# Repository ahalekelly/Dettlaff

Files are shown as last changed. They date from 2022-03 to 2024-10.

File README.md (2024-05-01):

# Dettlaff

Dettlaff is a modular controller system for brushless flywheel Nerf blasters



## Flashing Firmware over USB:
1. Install [VSCode]([https://platformio.org/install/ide?install=vscode](https://code.visualstudio.com/)) and [git](https://git-scm.com/downloads). On Windows you have to install [drivers for the CH340 USB adapter](https://learn.sparkfun.com/tutorials/how-to-install-ch340-drivers/all#drivers-if-you-need-them)
2. Download this repository, under the green Code button on this page, then in VSCode go to File > Open Folder and select the Dettlaff folder. If you downloaded the zip file then you need to select the inner Dettlaff folder, not the outer one. It will ask you to install the PlatformIO extension if you don't already have it
3. Power Dettlaff from a battery, and plug the USB adapter into your computer. There are 6 pins on the programmer that connect to 6 holes on the edge of Dettlaff, line up the pin with the square pad on the programmer with the hole with the square pad on Dettlaff, and insert the pins into the holes. Use the weight of the USB cable to apply a little torque to the adapter so that the pins make good contact, or solder a female header connector into the Dettlaff holes.
4. Update src/CONFIGURATION.h with your wifi name and password, and version of the board that you have, and any other settings for your blaster and then press the Upload button (arrow on the bottom toolbar)

USB Troubleshooting:

Dettlaff should enter upload mode automatically, but if it doesn't, the button on board can do it manually
* Try holding the button on the board as you hit upload, and keep holding until it says Uploading
* Try holding the button as you plug in the battery to Dettlaff, then letting go

## Flashing Firmware over WiFi:

1. First, flash a firmware over USB with your wifi SSID and password
2. In VSCode, change the Project Environment (button that says "Default" on the bottom toolbar) to "env:esp32-wifi"
3. Turn on or power cycle (unplug, wait a few seconds, and plug back in) your Dettlaff
4. Hit Upload within a few minutes of power cycling

## Wiring
* Look up in boards_config.h which pins to use for your version of Dettlaff
* Connect each switch between the numbered pin (yellow wire) and the - pin (black wire) on each connector
* Dettlaff is designed for the ESCs that we sell, but ESC connectors are not standardized. If you are using a different ESC, double check that all the pins on the ESC output match the pins on the ESC before connecting them! **This can fry your Dettlaff!**
* If you have a power switch, solder it between the - pin and the SHDN (shutdown) pin
* Solder your Dettlaff to the ESC and LiPo battery like below. The ground wire should go from the battery to the ESC, then from the ESC to the Dettlaff
imgonline-com-ua-twotoone-U4kocRnWdYJE

* Use the capacitors that came with the Dettlaff and the ESC. Use of capacitors with lower capacity or higher ESR could result in damage and will void your warranty

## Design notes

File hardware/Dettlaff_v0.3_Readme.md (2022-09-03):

## Flashing Instructions:
1. [Install VSCode and the PlatformIO Extension](https://platformio.org/install/ide?install=vscode)
2. Linux and Mac come with the CH340G serial adapter drivers, on Windows you can install them from [here](https://sparks.gogo.co.nz/assets/_site_/downloads/CH34x_Install_Windows_v3_4.zip)
3. Use `git clone`, Github Desktop, or VSCode to download this repository. **Github's Download Zip button does not include the required libraries!**
4. Open the Dettlaff directory in VSCode, set your WiFi SSID and password in the source code so that you can program over wifi later
5. On the bottom bar, click `Default (Dettlaff)` and select `env:esp32-usb` for USB programming
6. Power your Dettlaff from a battery, connect the USB-C adapter to your computer, insert the adapter pins into the holes and let the adapter rest at an angle (no need to solder), and hit the PlatformIO: Upload button on the bottom bar (the arrow)

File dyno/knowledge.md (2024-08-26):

# dyno Knowledge

## Purpose
- The dyno script is used for plotting dynamometer data for the Dettlaff project

## Key Features
- Reads data from a log file or serial port
- Supports multiple motors (determined dynamically from the data)
- Plots voltage, current, throttle, and RPM data
- Saves plots as PNG files

## Usage
- Can be run with a log file: `venv/bin/python dyno.py [logfile]`
- Can also capture real-time data from a serial port

## Dependencies
- matplotlib
- pyserial

## Environment
- Uses a Python virtual environment (venv)
- Requirements are specified in requirements.txt

## Important Notes
- The script doesn't exit until the user quits it
- Code changes cannot be applied while the script is running

## TODO
- Consider optimizing the plot saving process (currently saves twice)
- Explore adding more analysis features or statistics from the data

# Python Virtual Environment Instructions:

`cd` to the dyno directory

## Setup:

Create a new venv called venv:
    python3 -m venv venv

Install requirements inside that venv:
    venv/bin/python -m pip install -r requirements.txt

## Usage:

To capture and plot the serial telemetry, run 
    venv/bin/python dyno.py

If you want to also print the serial data while it's coming in:
    venv/bin/python dyno.py -p

To regenerate the plot for an existing log file:
    venv/bin/python dyno.py 2024-08-25_21:30:04.log

To regenerate the plots for all log files:
    venv/bin/python dyno.py all

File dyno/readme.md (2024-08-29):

# Dettlaff Dynamometer

Captures telemetry data over the serial bus, saves it to a .log file, and plots it to a .png file



## Setup:

Make sure you have python installed

`cd` to the dyno directory

Create a new venv called venv and install the requirements:

    python3 -m venv venv && venv/bin/python -m pip install -r requirements.txt

## Usage Examples:

`cd` to the dyno directory

To capture and plot the serial telemetry:

    venv/bin/python dyno.py

To regenerate the png files for all log files - the formatting on the real-time plots is a little off right now, this will fix them

    venv/bin/python dyno.py -a

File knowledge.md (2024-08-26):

# Dettlaff Project Knowledge

## Project Overview
- Dettlaff is a modular controller system for brushless flywheel Nerf blasters
- The project includes hardware designs and software for controlling and monitoring the blaster

## Key Components
- dyno: A Python script for plotting dynamometer data
- src: Contains the main source code for the controller
- hardware: Contains hardware designs and documentation

## Development Environment
- Uses PlatformIO for embedded development
- Python virtual environment for dyno script

## Flashing Instructions
- Firmware can be flashed over USB or WiFi
- Requires VSCode with PlatformIO extension

## Wiring
- Specific wiring instructions are provided in the README
- Caution is needed when connecting ESCs to avoid damage

## TODO
- Add more detailed information about the src and hardware components as they are explored

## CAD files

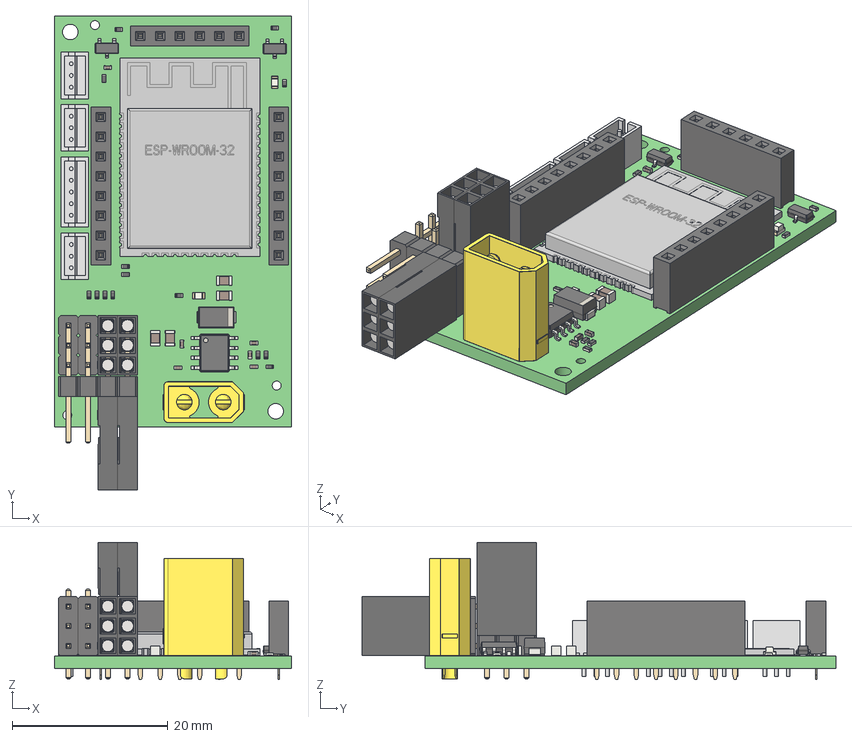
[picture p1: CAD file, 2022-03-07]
hardware/Core_v0.1/Dettlaff_Core_v0.1.step
30.5 x 60.9 x 17.6 mm
RapidstrikePCB PCB
PinHeader_3x04_P2.54mm_Horizontal
DS1071-1x3 x 4

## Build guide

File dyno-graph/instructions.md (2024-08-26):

Python Virtual Environment Instructions:

`cd` to the dyno-graph directory

# Setup:

Create a new venv called venv:
    python3 -m venv venv

Install requirements inside that venv:
    venv/bin/python -m pip install -r requirements.txt

# Usage:

To capture and plot the serial telemetry, run 
    venv/bin/python dyno-graph.py

If you want to also print the serial data while it's coming in:
    venv/bin/python dyno-graph.py -p

To regenerate the plot for an existing log file:
    venv/bin/python dyno-graph.py 2024-08-25_21:30:04.log

To regenerate the plots for all log files:
    venv/bin/python dyno-graph.py -a

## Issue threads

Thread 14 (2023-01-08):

To Do: Design adapter board for 2 individual ESCs

ahalekelly, 2023-01-08:

Daehder, 2023-01-10:
You may not need a board; didn't Eli say that you could get a Chinese factory to crimp cables for you? It's pretty simple to make a simple wiring adaptor for this; I can post pictures later

ahalekelly, 2023-01-11:
Oh yeah that's a pretty good idea! I must have missed where Eli suggested that. I'll look into it.

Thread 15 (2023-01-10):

Have current firing mode update over BLE

Daehder, 2023-01-10:
It would be pretty neat if the current firing mode could update on the web app; users could then have a couple picked out to switch between and do so with a tap.

We might need a special "updatable" proto message

ahalekelly, 2023-01-11:
Good point! We definitely need a currentFiringMode parameter in the protobuf. Not sure what you mean by an "updatable" proto message

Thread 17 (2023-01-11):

To Do: Reverse pusher motor direction during braking

ahalekelly, 2023-01-11:
If the braking torque of the motor is not enough, you could apply reverse voltage instead of braking to stop it faster, or you could brake normally and reverse the motor if the pusher overruns and the cycle control switch becomes released

1) When cycle control switch is pressed, (maybe stop applying voltage to the pusher and wait a few ms to allow inductive field to decay faster than reverse polarity? should test whether this helps), then apply reverse polarity to pusher
2) After `pusherReversePolarityDuration_ms` time has passed, if cycle control switch is still pressed, remove reverse polarity and brake pusher
3) If `pusherReverseOnOverrun` config flag is set and cycle control switch is no longer pressed, maintain reverse polarity until switch becomes pressed again, then brake

I don't think we need a separate pusher control mode from the current PUSHER_MOTOR_CLOSEDLOOP mode, I think if you set duration to 0 and and the config flag to false then it would operate the same as the current mode?

It might be possible to automatically determine these variables through trial and error? Start with 0ms reverse polarity duration, and every time you see a pusher overrun, increase the duration by 1ms, up to some cap?

ahalekelly, 2023-04-17:
Another idea to prevent pusher runaway is to drive the pusher for a shorter period of time, or at a lower voltage level

ahalekelly, 2024-04-20:
This has been implemented but you have to manually tune it, and the proper value for pusherReversePolarityDuration_ms depends on how many darts you fired and whether you have darts left in the mag. We have current monitoring for the pusher now, can you determine the motor speed from the current and voltage and figure out when it's stopped?

Also there were lots of bugs when you enable pusherReverseOnOverrun and/or pusherEndReverseBrakingEarly I don't remember.

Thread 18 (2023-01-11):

To Do: Power savings

ahalekelly, 2023-01-11:
Turn off ESC and sleep Dettlaff when not in use
Notify user when battery voltage is low and then turn off ESC and sleep Dettlaff

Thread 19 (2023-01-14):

To Do: Tournament Lock

Daehder, 2023-01-14:
Ideally, we would have some way for a tournament organizer/staff to lock the fps (and rate of fire?) while still allowing the user to make and adjust firing modes.

This needs to
- Persist through a power cycle
    - both for legitimate battery changes and to foil bypass attempts
- Probably needs a timeout so that organizers don't need to publish said code or manually unlock devices
    - Doing this well could be challenging
        - A real time clock could let us set a timeout by wall clock time, but needs a battery that could complicate things
        - We could use clock time from the user's phone, but what happens if they take their phone offline and set the clock differently?
        - We could set up a server (/ serverless function?) that lets an organizer register their tournament's start time, end time, and limits, then lock the user's detlaff to that until their phone can query said server to see if it's okay to unlock?
            - This does mean someone could get stuck in a tournament lock if they leave early and can't undo it
 - Does Detlaff need to periodically advertise its state, tournament locked or not?

This might be simple enough with a code entered though the web app

This would probably be handled better through an event-organizer-specific web app; We'll see how far that gets

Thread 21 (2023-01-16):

Todo Figure out Spindown logic

Daehder, 2023-01-16:
We've got a placeholder value for spin down logic in the flywheel proto; we should figure out how we want to use that and update the documentation with units and/or an explanation when we do.

ahalekelly, 2023-01-17:
Currently the units are throttle units (scale of 0-1999) per control loop (which currently targets 1ms), [see here](https://github.com/ahalekelly/Dettlaff/blob/8f19ec03f7ce4ca9c4b30c1bc7d2380553e2c2fc/src/main.cpp#L248)
This is a crude method, we could do rpm per second, or some exponential scale like percent of current value per second, with some minimum rate so you don't asymptotically approach zero. I'll probably try the latter at some point and see whether I prefer linear or exponential. But this is a very minor feature.

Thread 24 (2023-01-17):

TODO: Flesh out UX options

Daehder, 2023-01-17:
People will want / have been asking for all sorts of ux options like rotational switches, quick setting buttons, screens, dpads like the PewPew, etc

```Also we need an option to have a button that will jump to a specific fire mode instead of cycling through modes - should this be a parameter in each FireModeEntry, or a repeated value in ControlParams? Each button will need a pin and SwitchOrientation``

_Originally posted by @ahalekelly in https://github.com/ahalekelly/Dettlaff/pull/2#discussion_r1071784529_

ahalekelly, 2023-01-21:
Yeah from an electrical/firmware standpoint, I think having one button per fire mode is equivalent to a rotary switch. So you can have one firmware mode for both of those which I described above.

Maybe people want Next Fire Mode and Prev Fire Mode buttons, instead of a single Cycle Fire Mode button? Also for a single Cycle Fire Mode button to work, you need to have a way of knowing what fire mode you're in. We should make the ESCs beep an identifiable pattern when changing to a fire mode, that's possible to do over dshot though I'm not sure you can do it while the motors are spinning. Or maybe blink the white LED in a pattern?

SuperStressed just brought up that the Hummingbird has a dual stage trigger, where the first stage is semi auto and second stage is full auto. I hadn't thought of this scenario before, need to figure out the best way to encode that in the protobuf. Maybe just a boolean to make the button for each fire mode also act as a trigger?

And we should also support rate of fire adjustment with a potentiometer. That's a super straightforward thing, just have parameters for potMinRof and potMaxRof and scale between them. I think log scale is preferable here, maybe people can just buy a log pot though?

I wasn't planning on writing the firmware for a screen, but I've been very surprised how many people have been asking for a screen. It's at least out of scope for now though. And I think dpads and rotary encoders are only useful if you have a screen?

Also, Ray brought up that it would be cool to be able to fire the blaster remotely over BLE. Changing the active fire mode is definitely required too.

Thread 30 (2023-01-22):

To Do: Screen UI

ahalekelly, 2023-01-22:
The PCB has an I2C connector for a small OLED screen or other accessories (see the [Narfduino Console](https://blastersbyairzone.com/hardware/narfduino-console/)), but I'm not currently planning on writing the UI for a screen. Lots of people seem to want it, this would be a good project for someone to take on as it's reasonably self-contained.

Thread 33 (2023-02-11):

Determine if/how ESP32 and Web BLE libraries handle packets larger than 512 bytes

Daehder, 2023-02-11:
BLE only natively supports packets as large as 512 bytes; NanoPB is calculating that the Blaster proto has a max size that exceeds 600 bytes (and I need to add support for independent RPMS for each motor, so it will get larger).

I need to look at the ESP32 library to see if it has any expected way to handle packets that are too large for one method; @ahalekelly can you check how your webBLE handles that?

If it's missing from either or they have incompatible mechanisms, we might need to implement our own version of that

ahalekelly, 2023-02-11:
Wow how did it get so big? Does it tell you the size of each field?

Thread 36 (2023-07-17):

Todo: Rev logic on startup

ahalekelly, 2023-07-17:
Need to check whether pressing the trigger soon after startup prevents ESCs from arming

Also someone requested a switch to make the flywheels idle all the time

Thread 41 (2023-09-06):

Out of memory errors?

ahalekelly, 2023-09-06:
This happens when you use bidirectional dshot and PID and wifi at the same time:

```
assert failed: rmt_isr_handle_rx_done rmt_rx.c:505 (offset > rx_chan->mem_off)

Backtrace: 0x40083715:0x3ffbf4ec |<-CORRUPTED

ELF file SHA256: ca134528bf1404a7

Rebooting...
```

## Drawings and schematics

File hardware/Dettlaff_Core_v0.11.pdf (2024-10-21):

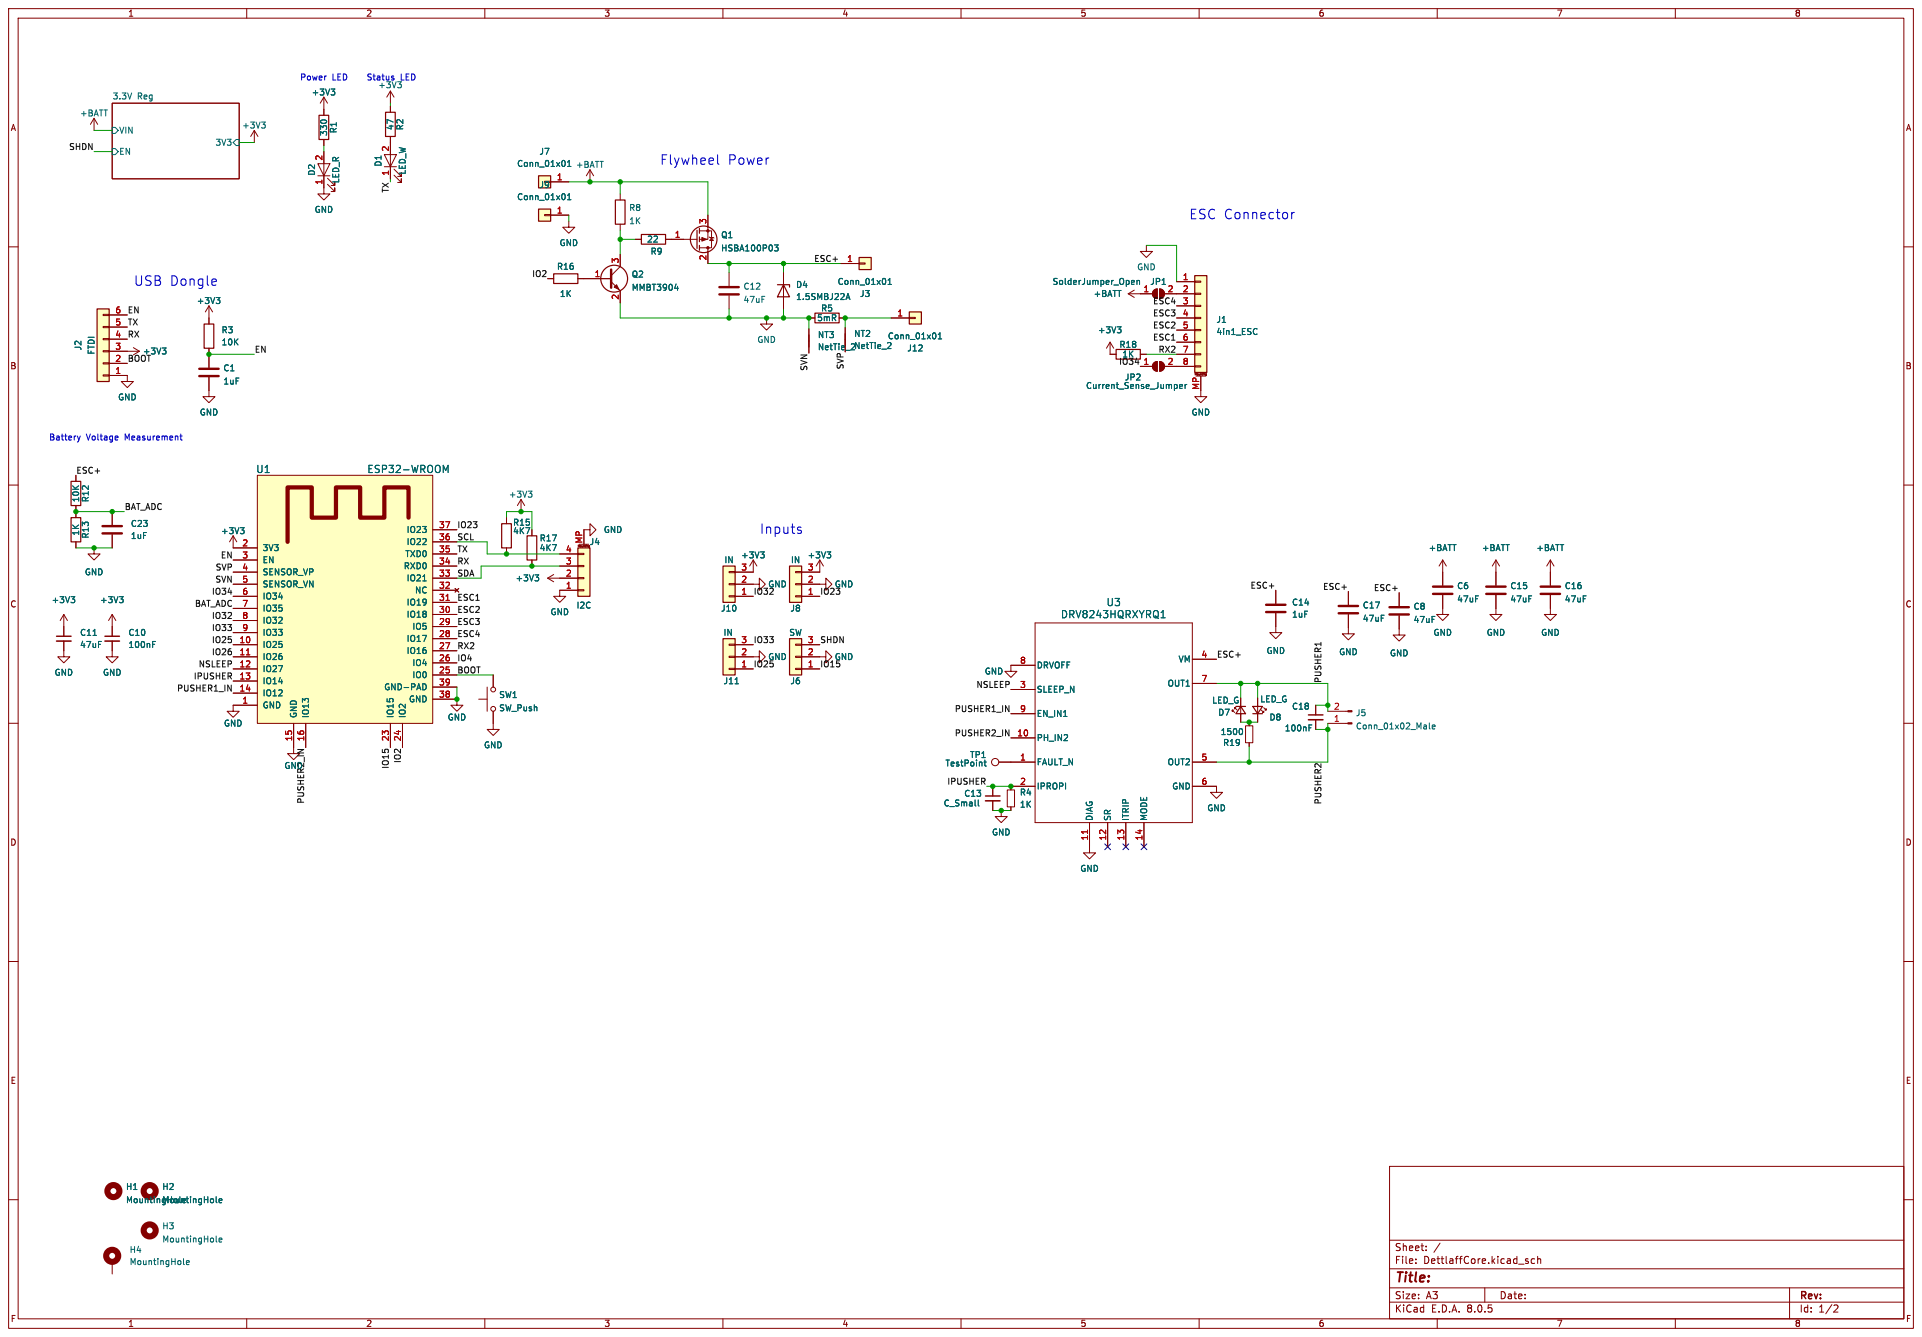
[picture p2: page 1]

2 3 Q1 HSBA100P03 +BATT GND GND GND

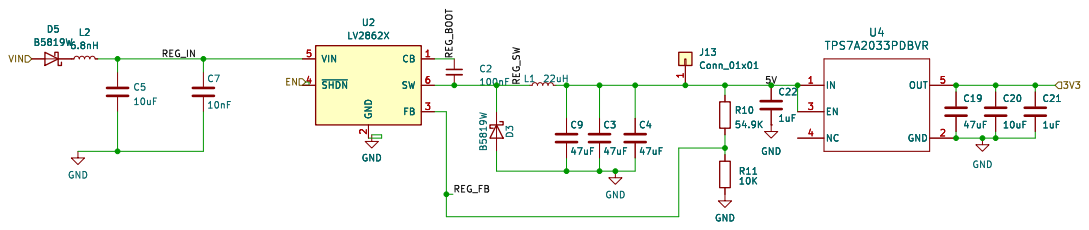
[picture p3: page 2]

2 FB 3 ~{SHDN} 4 VIN 5 SW 6 U2

2 FB 3 ~{SHDN} 4 VIN 5 SW 6

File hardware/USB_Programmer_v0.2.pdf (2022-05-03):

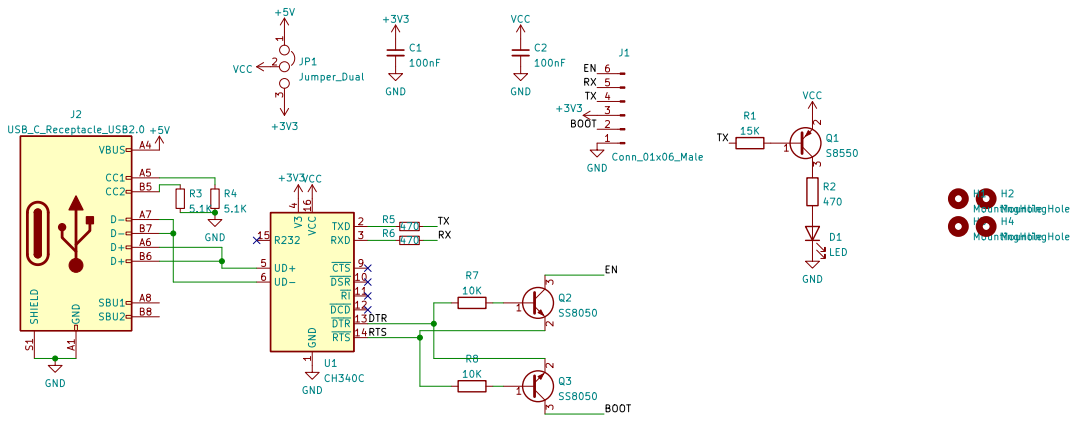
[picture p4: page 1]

4 UD+ 5 UD- 6 ~{CTS} 9 U1CH340C GND

1 ~{DSR}10 ~{RI}11 ~{DCD}12 ~{DTR}13 ~{RTS}14 R232 15 VCC 16 TXD 2 RXD 3 V3

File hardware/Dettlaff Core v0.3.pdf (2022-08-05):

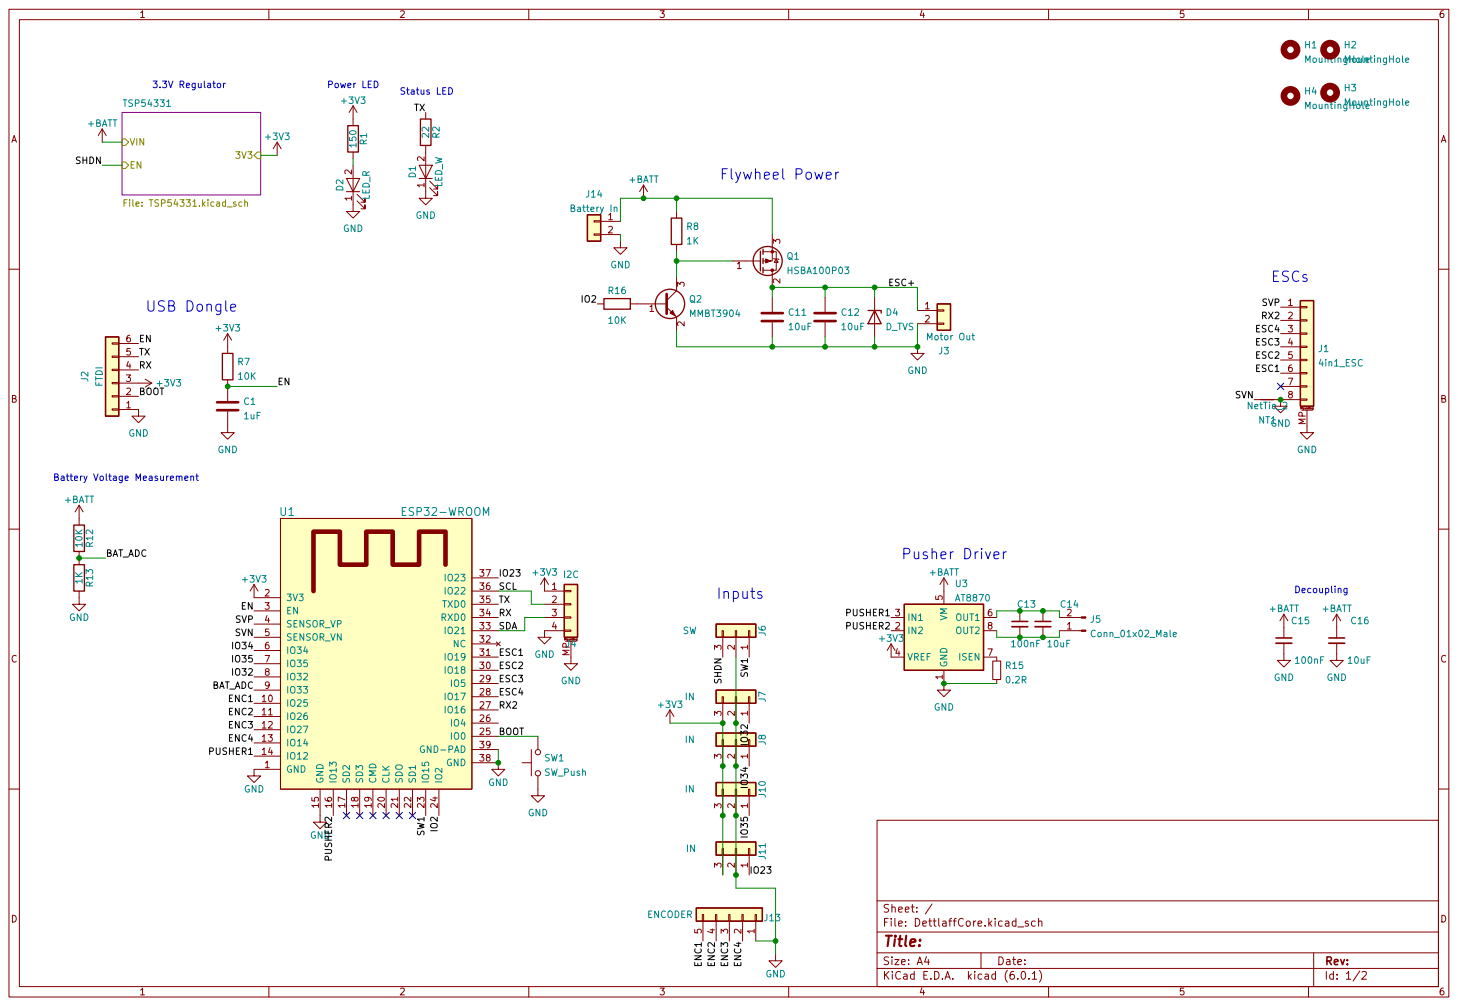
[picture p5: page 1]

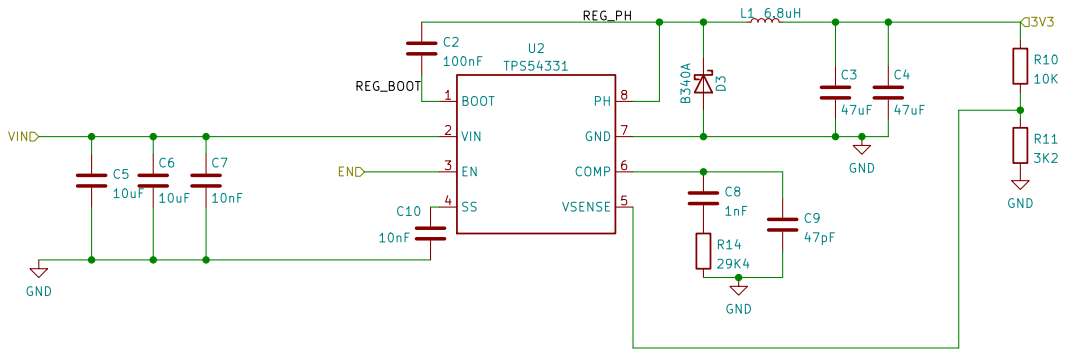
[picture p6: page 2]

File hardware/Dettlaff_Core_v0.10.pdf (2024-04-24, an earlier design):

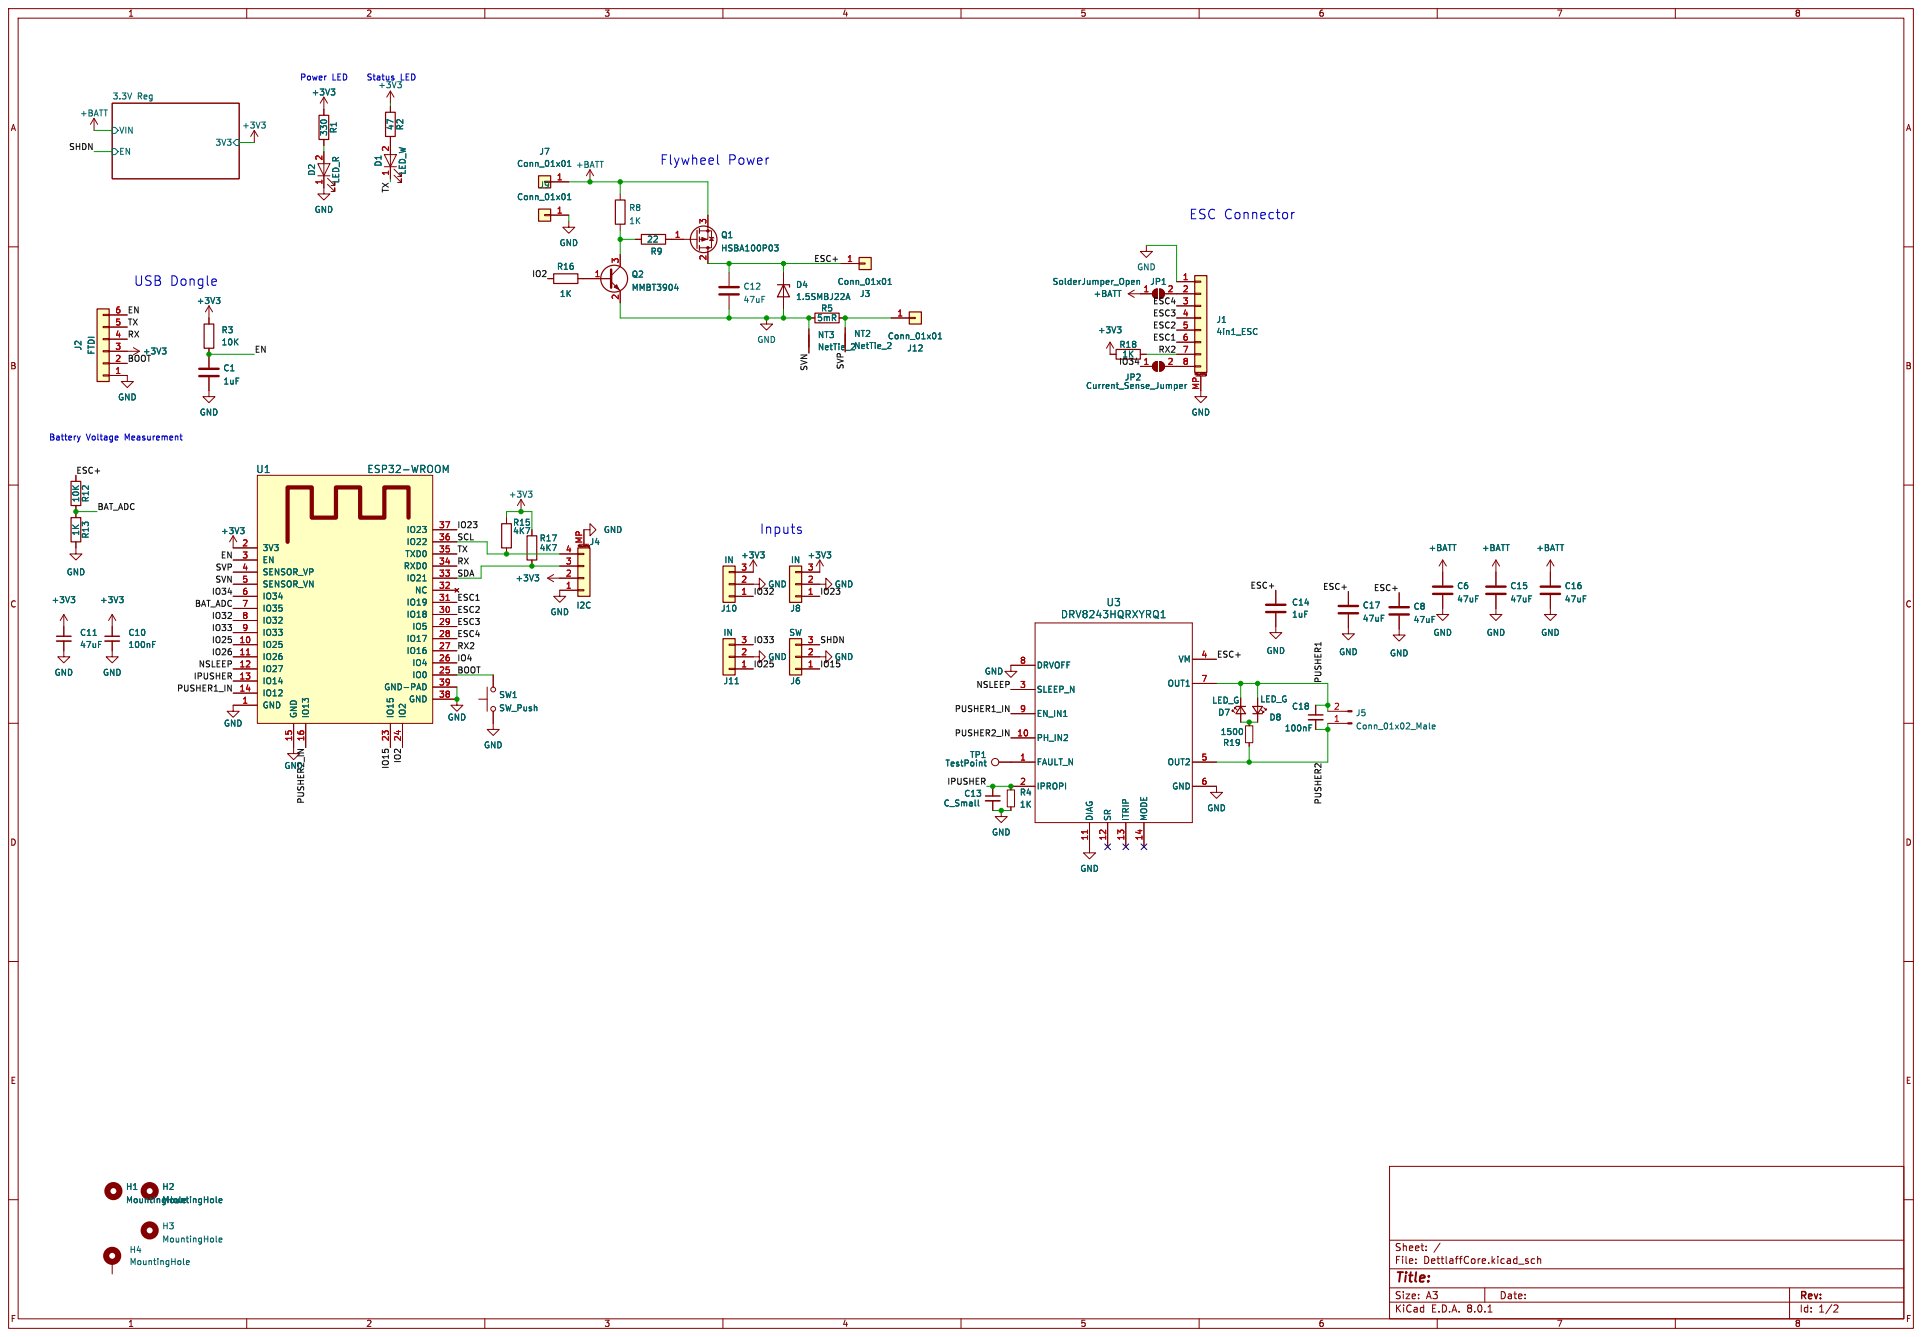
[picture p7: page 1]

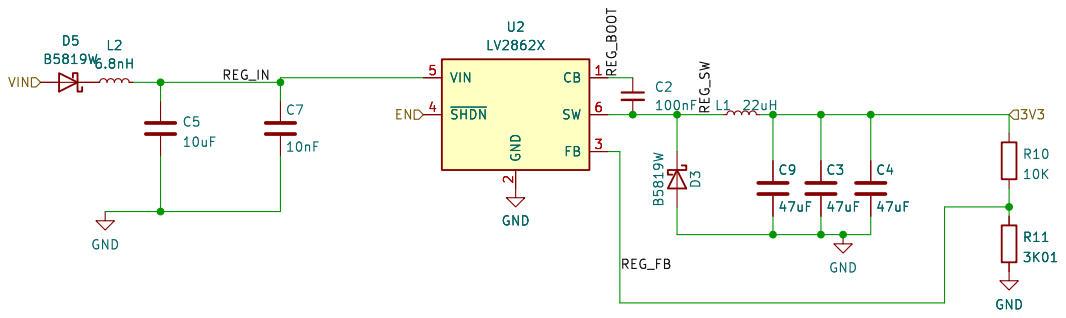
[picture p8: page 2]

2 FB 3 ~{SHDN} 4 VIN 5 SW 6 U2
LV2862X GND

2 FB 3 ~{SHDN} 4 VIN 5 SW 6

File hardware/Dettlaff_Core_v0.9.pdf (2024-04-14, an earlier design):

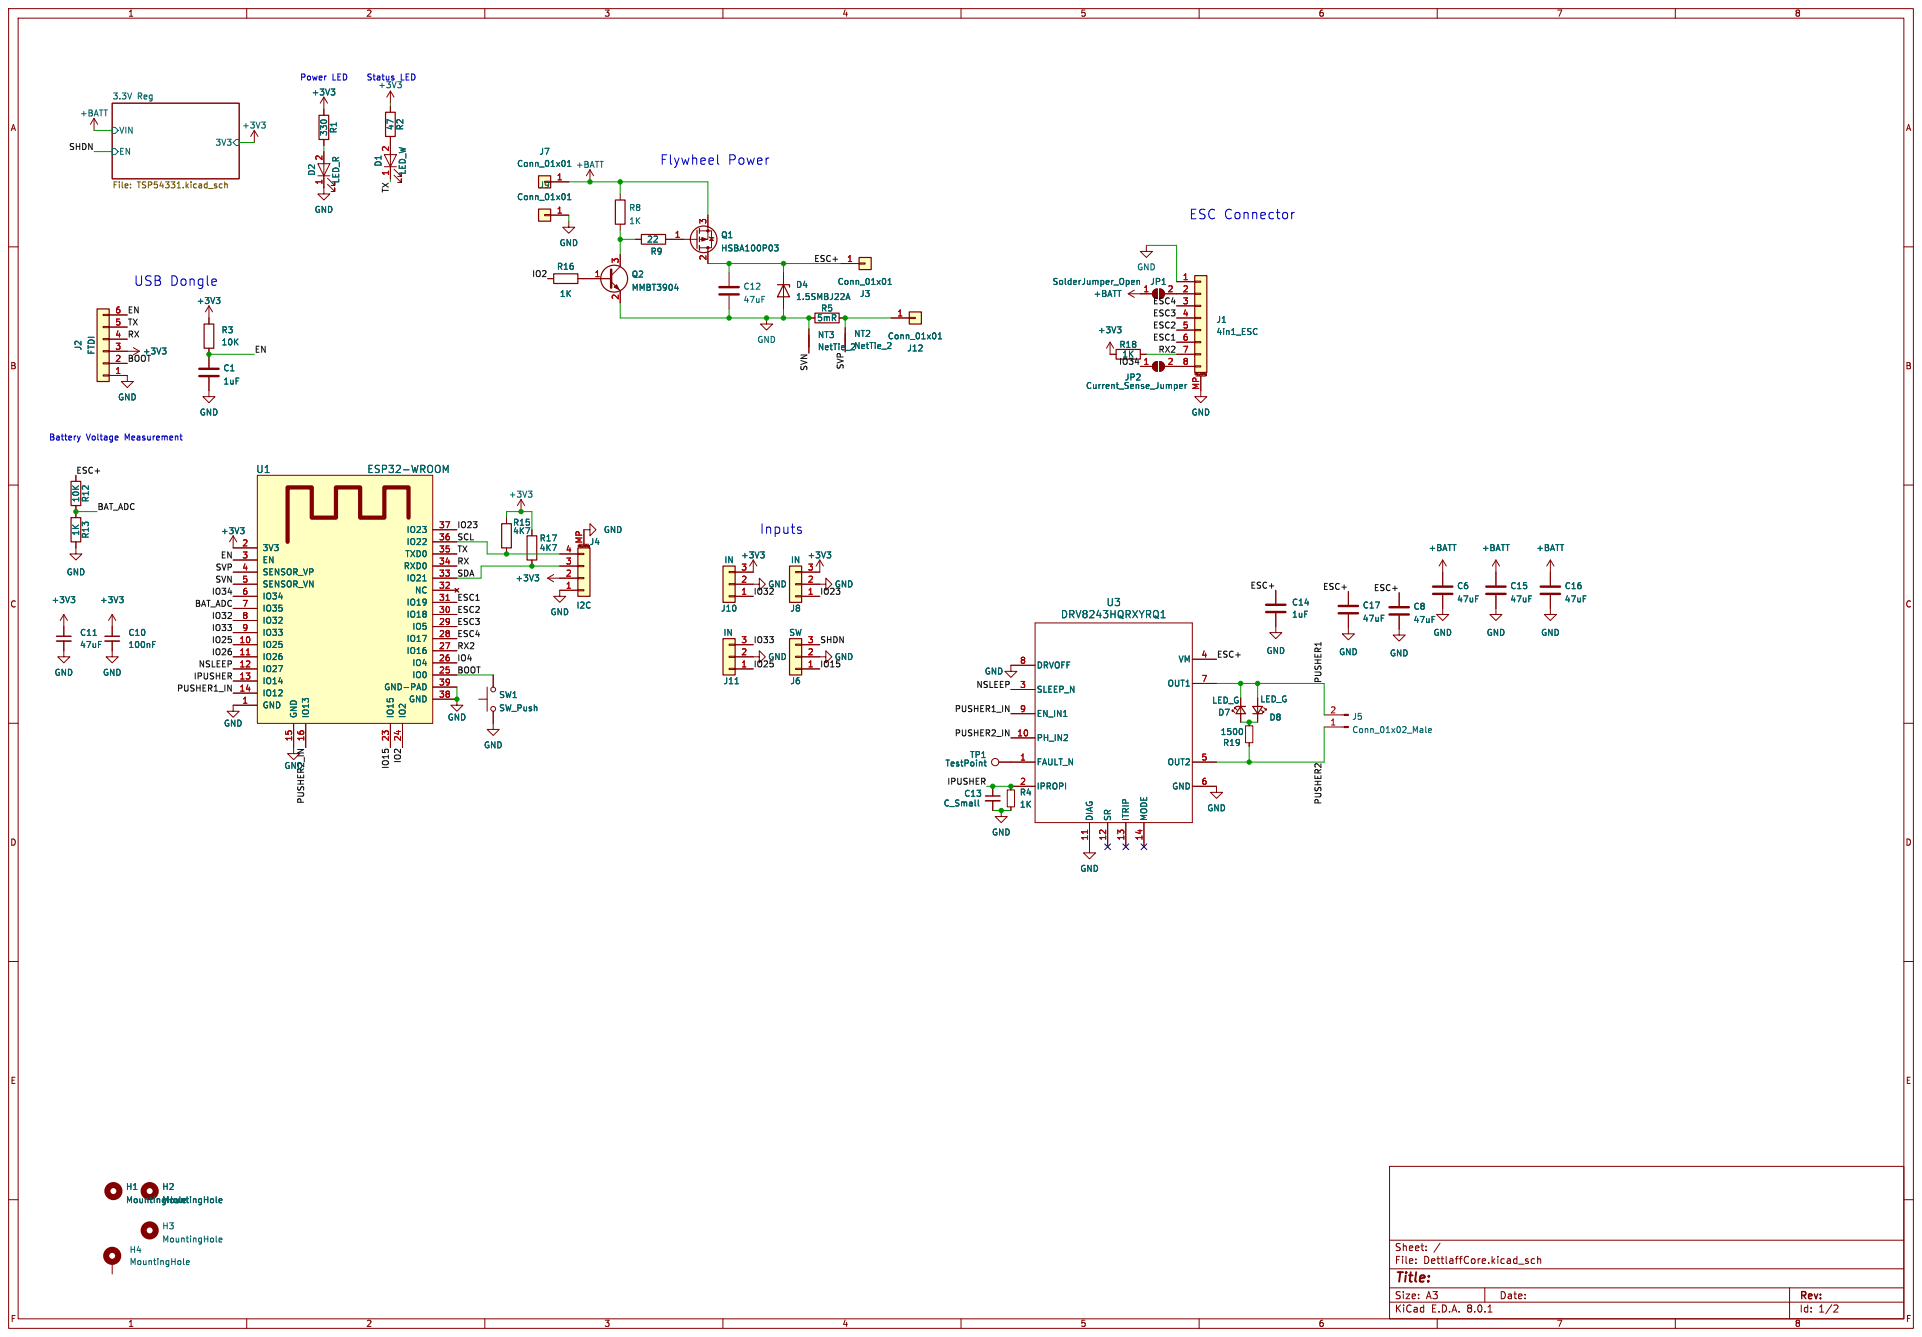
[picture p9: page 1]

H4 MountingHole H1 MountingHole H2 MountingHole H3 MountingHole

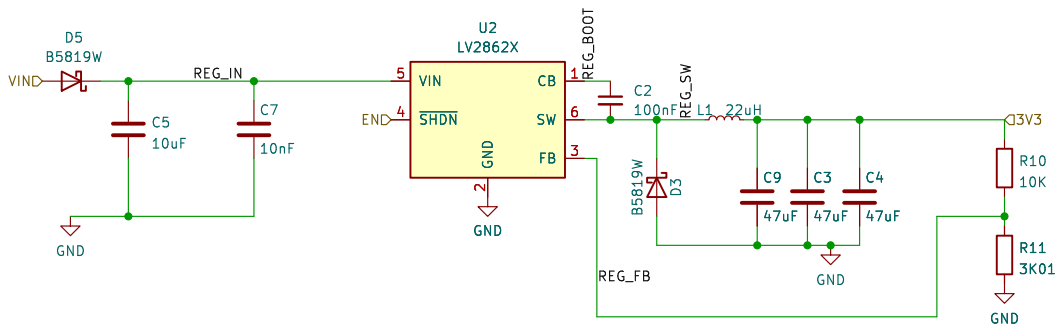
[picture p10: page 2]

2 FB 3 ~{SHDN} 4 VIN 5 SW 6 U2
LV2862X GND

2 FB 3 ~{SHDN} 4 VIN 5 SW 6

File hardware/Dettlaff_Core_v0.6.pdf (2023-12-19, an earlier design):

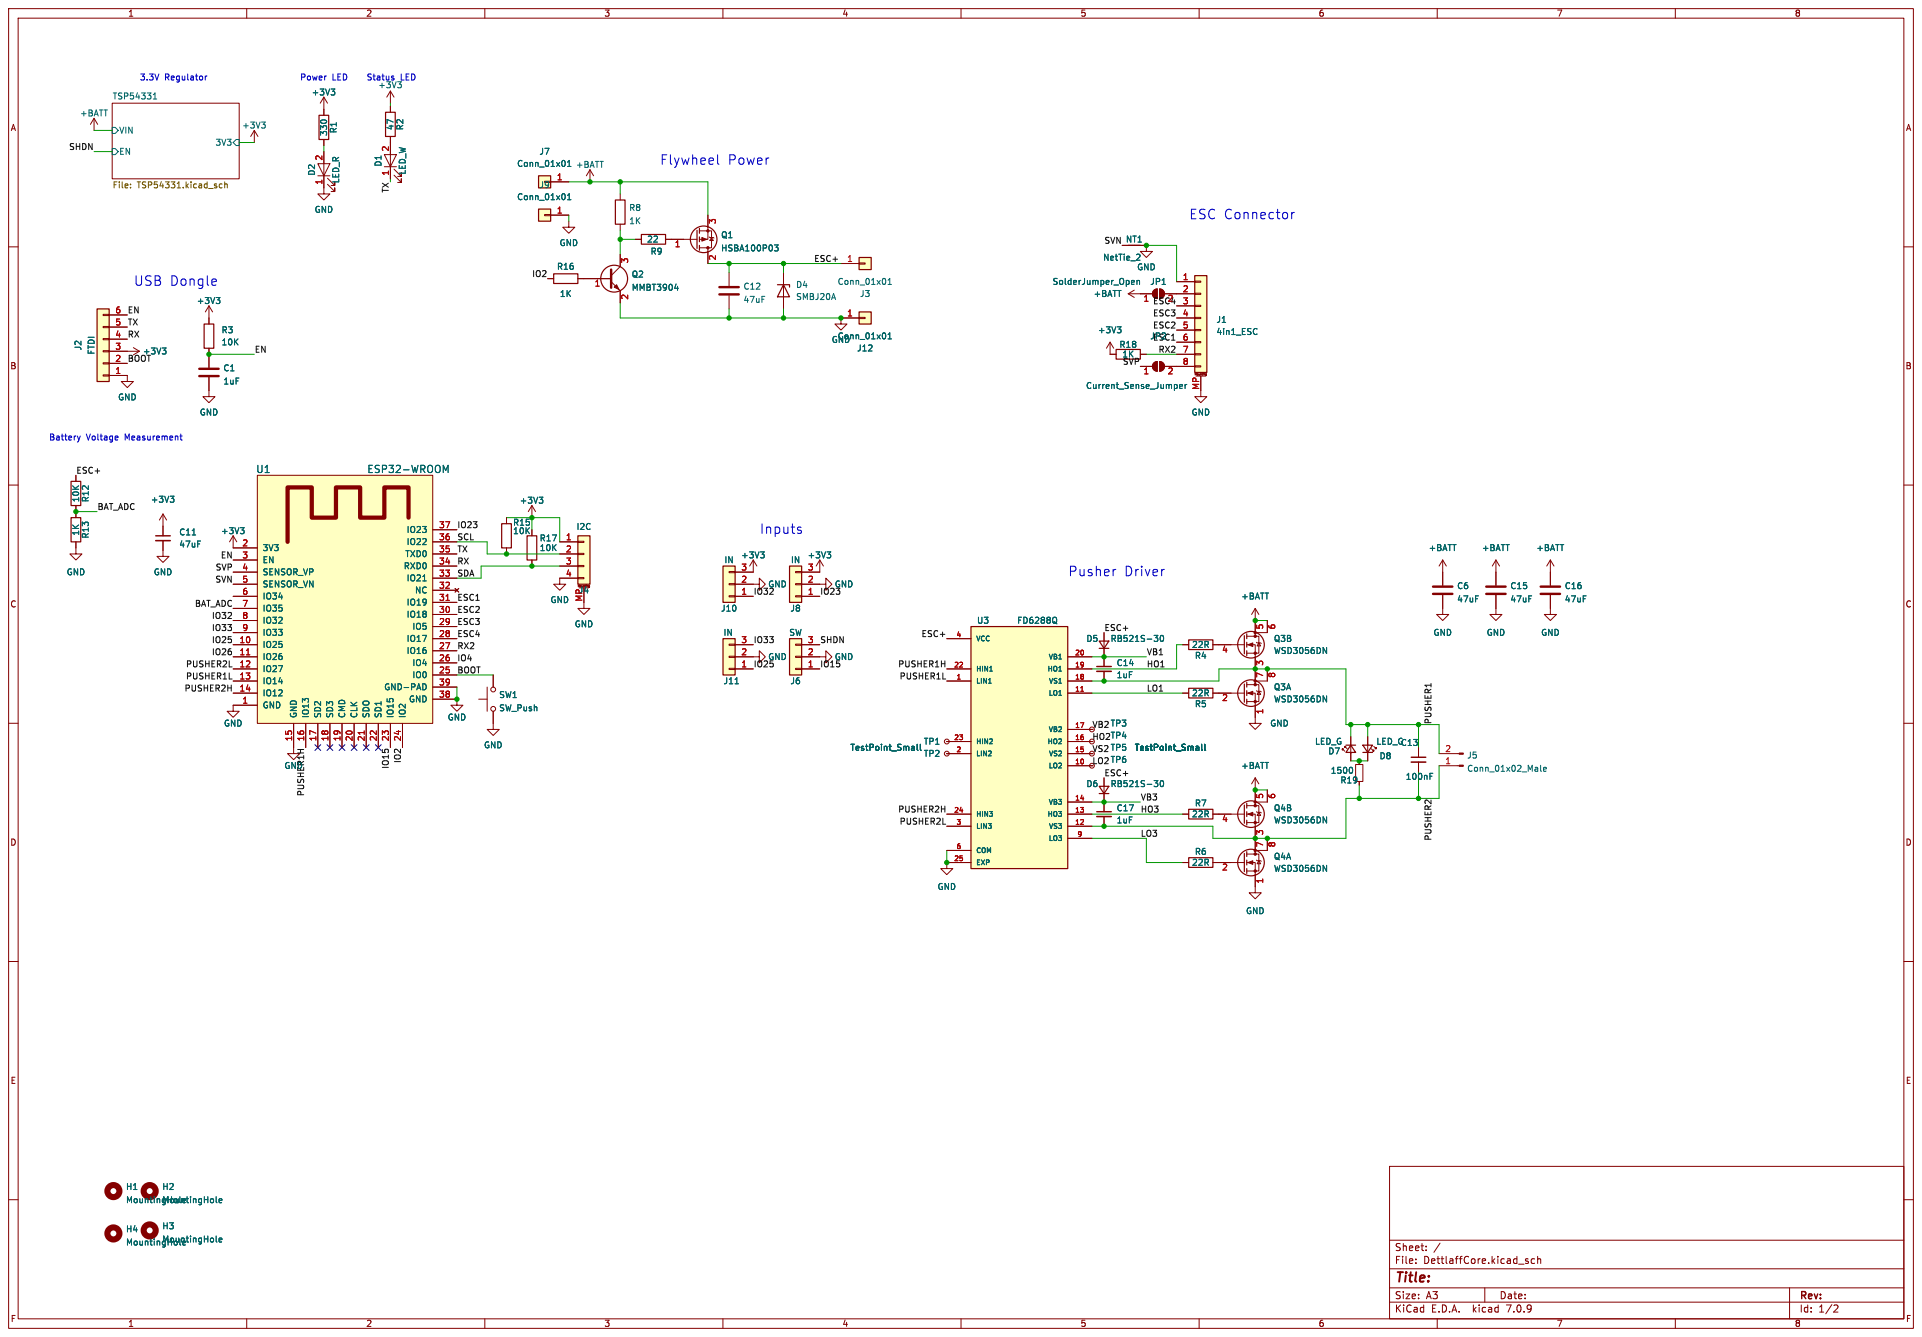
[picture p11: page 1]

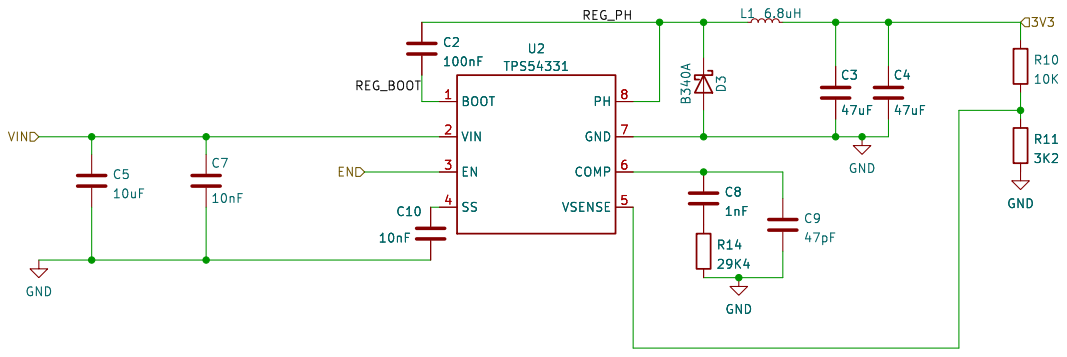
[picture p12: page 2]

Id: 2/2 Title: File: TSP54331.kicad_sch Sheet: /TSP54331/ C7

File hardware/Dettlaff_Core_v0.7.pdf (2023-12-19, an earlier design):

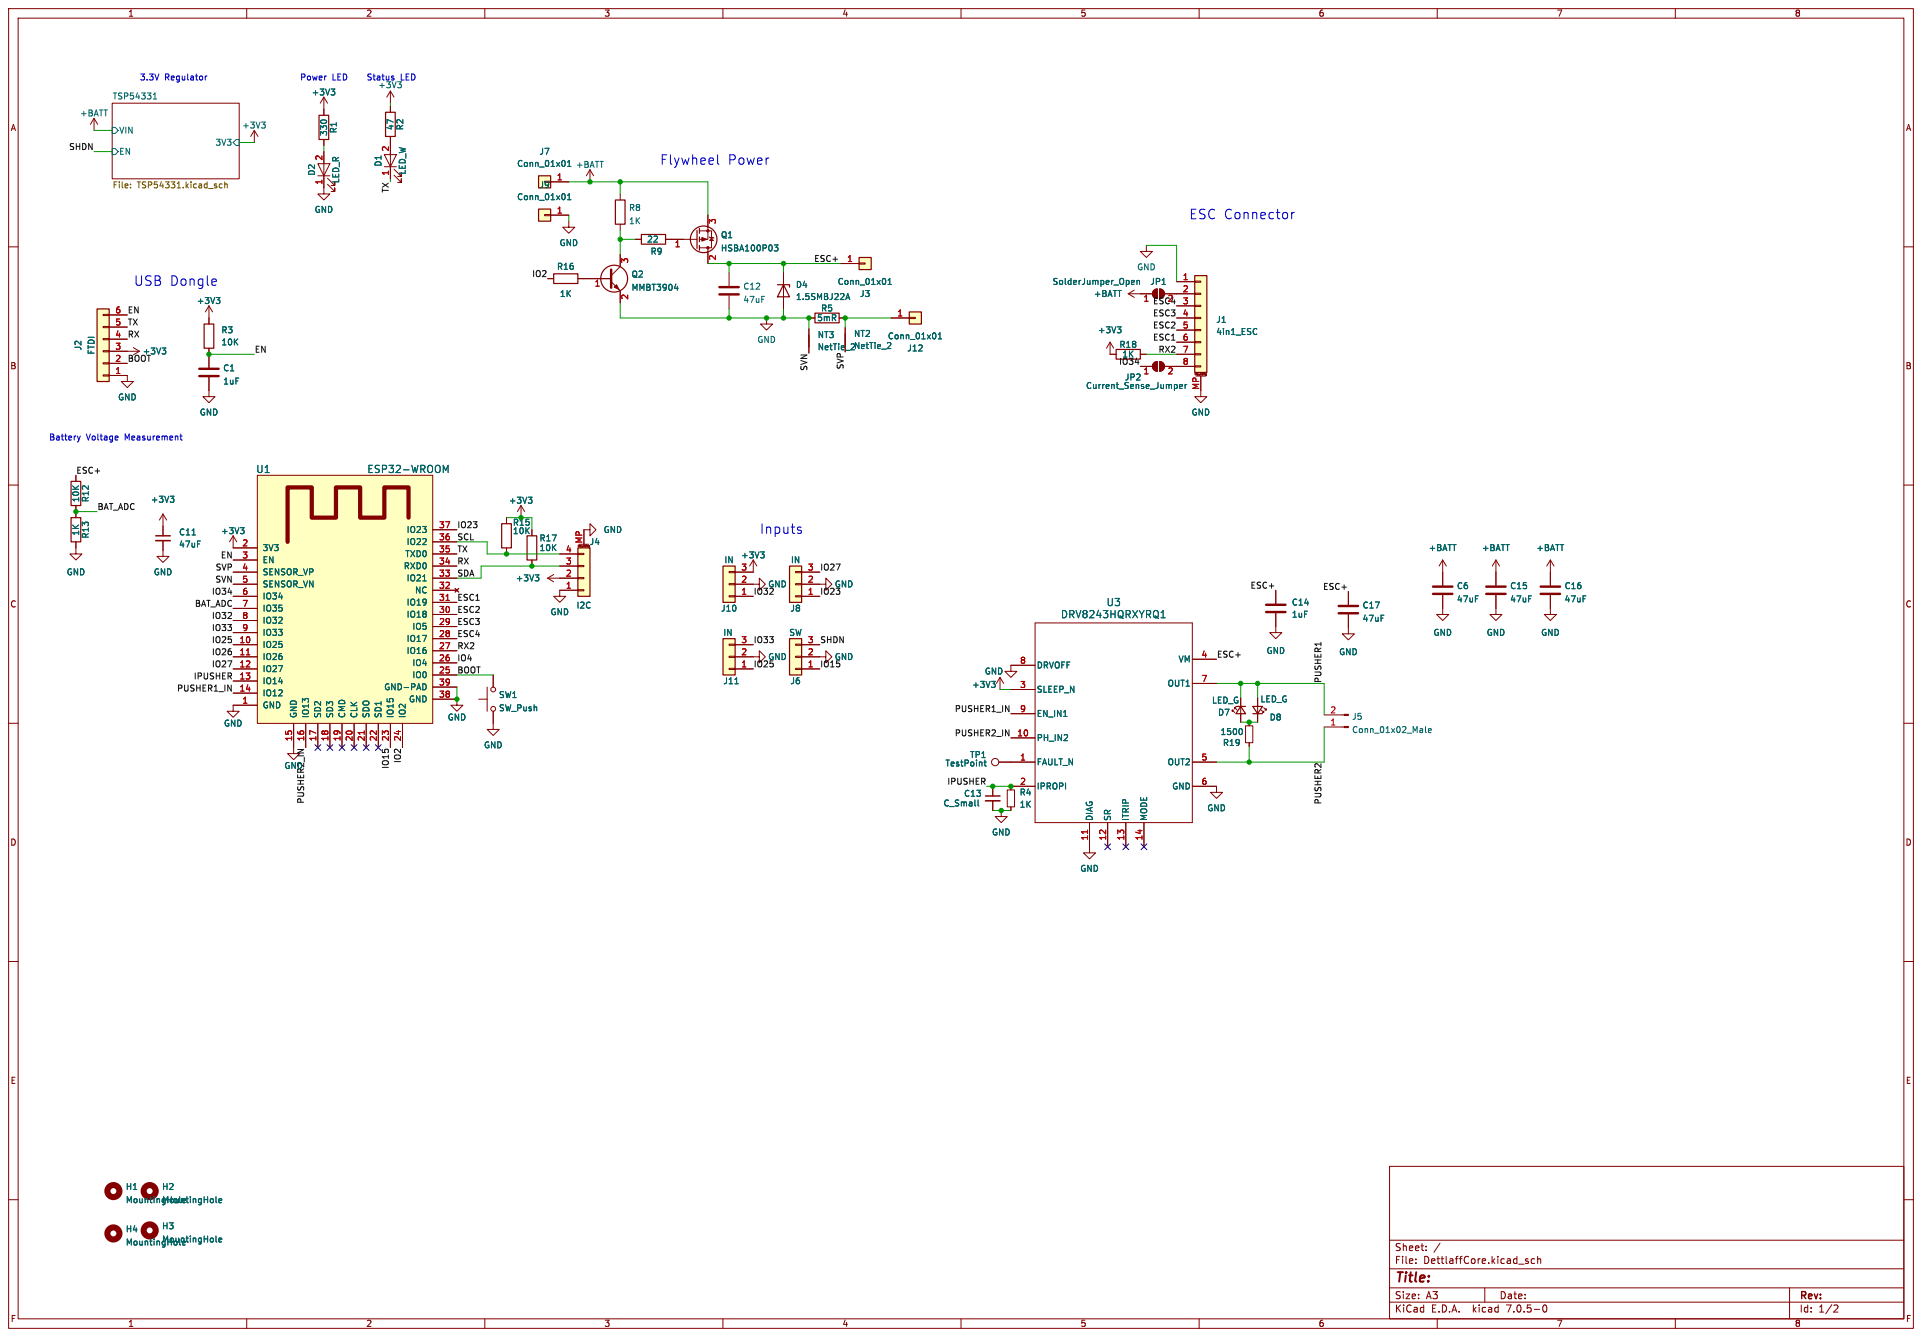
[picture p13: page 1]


Id: 2/2 Title: File: TSP54331.kicad_sch Sheet: /TSP54331/ C7

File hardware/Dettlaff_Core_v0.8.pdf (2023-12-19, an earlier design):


Battery Voltage Measurement USB Dongle
IO33 9 GND


Id: 2/2 Title: File: TSP54331.kicad_sch Sheet: /TSP54331/ C7

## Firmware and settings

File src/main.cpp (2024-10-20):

#include "Bounce2.h"
#include "CONFIGURATION.h"
#include "DShotRMT.h"
#include "ESP32Servo.h"
#include "driver.h"
#include "drvDriver.h"
#include "fetDriver.h"
#include "hBridgeDriver.h"
#include "types.h"
#include <Arduino.h>
#include <ArduinoOTA.h>
#include <ESP32AnalogRead.h>
#include <esp_wifi.h>

uint32_t loopStartTimer_us = micros();
uint32_t loopTime_us = targetLoopTime_us;
uint32_t time_ms = millis();
uint32_t lastRevTime_ms = 0; // for calculating idling
uint32_t pusherTimer_ms = 0;
int32_t revRPM[4]; // stores value from revRPMSet on boot for current firing mode
int32_t idleTime_ms; // stores value from idleTimeSet_ms on boot for current firing mode
int32_t targetRPM[4] = { 0, 0, 0, 0 }; // stores current target rpm
int32_t firingRPM[4];
int32_t throttleValue[4] = { 0, 0, 0, 0 }; // scale is 0 - 1999
uint32_t currentSpindownSpeed = 0;
uint16_t burstLength; // stores value from burstLengthSet for current firing mode
burstFireType_t burstMode; // stores value from burstModeSet for current firing mode
int8_t firingMode = 0; // current firing mode
int8_t fpsMode = 0; // copy of firingMode locked at boot
bool fromIdle;
bidirectional_mode_e dshotBidirectional = NO_BIDIRECTION;
int32_t dshotValue = 0;
int16_t shotsToFire = 0;
flywheelState_t flywheelState = STATE_IDLE;
bool firing = false;
bool reverseBraking = false;
bool pusherDwelling = false;
uint32_t batteryADC_mv = 0;
int32_t batteryVoltage_mv = 14800;
int32_t voltageBuffer[voltageAveragingWindow] = { 0 };
int voltageBufferIndex = 0;
int32_t pusherShunt_mv = 0;
int32_t pusherCurrent_ma = 0;
int32_t pusherCurrentSmoothed_ma = 0;
const int32_t maxThrottle = 1999;
int32_t motorRPM[4] = { 0, 0, 0, 0 };
int32_t fullThrottleRpmThreshold[4] = { 0, 0, 0, 0 };
Driver* pusher;
bool wifiState = false;
// String telemBuffer = "";
int8_t telemMotorNum = -1; // 0-3
uint32_t revStartTime_us = 0;
uint32_t triggerTime_ms = 0;
int32_t tempRPM;
ESP32AnalogRead batteryADC;
ESP32AnalogRead pusherShuntADC;
bool currentlyLogging = false;

// closed loop variables
int32_t PIDError[4];
int32_t PIDErrorPrior[4];
int32_t closedLoopRPM[4];
int32_t PIDOutput[4];
int32_t PIDIntegral = 0;

Bounce2::Button revSwitch = Bounce2::Button();
Bounce2::Button triggerSwitch = Bounce2::Button();
Bounce2::Button cycleSwitch = Bounce2::Button();
Bounce2::Button button = Bounce2::Button();
Bounce2::Button select0 = Bounce2::Button();
Bounce2::Button select1 = Bounce2::Button();
Bounce2::Button select2 = Bounce2::Button();

// Declare servo variables for each motor.
Servo servo[4];
DShotRMT dshot[4] = {
    DShotRMT(board.esc1),
    DShotRMT(board.esc2),
    DShotRMT(board.esc3),
    DShotRMT(board.esc4)
};

void WiFiInit();
void updateFiringMode();

void setup()
{
    Serial.begin(460800);
    Serial.println("Booting");

    batteryADC.attach(board.batteryADC);
    batteryADC_mv = batteryADC.readMiliVolts();
    batteryVoltage_mv = voltageCalibrationFactor * batteryADC_mv * 11;
    Serial.print("Battery voltage (before calibration): ");
    Serial.println(batteryVoltage_mv);
    if (voltageCalibrationFactor != 1.0) {
        Serial.print("Battery voltage (after calibration): ");
        Serial.println(voltageCalibrationFactor * batteryADC_mv * 11);
    }

    if (flywheelControl != OPEN_LOOP_CONTROL || printTelemetry) {
        dshotBidirectional = ENABLE_BIDIRECTION;
    }

    switch (board.pusherDriverType) {
    case HBRIDGE_DRIVER:
        pusher = new Hbridge(board.pusher1H, board.pusher1L, board.pusher2H, board.pusher2L, maxDutyCycle_pct, pwmFreq_hz, deadtime);
        pusher->coast();
        break;
    case DRV_DRIVER:
        pusher = new Drv(board.pusher1L, board.pusher2L, pwmFreq_hz, board.pusherCoastHigh);
        break;
    case FET_DRIVER:
        pusher = new Fet(board.pusher1H);
        break;
    default:
        break;
    }

    // Serial2.begin(115200, SERIAL_8N1, board.telem, -1);
    // pinMode(board.telem, INPUT_PULLUP);

    if (revSwitchPin) {
        revSwitch.attach(revSwitchPin, INPUT_PULLUP);
        revSwitch.interval(debounceTime_ms);
        revSwitch.setPressedState(revSwitchNormallyClosed);
    }
    if (triggerSwitchPin) {
        triggerSwitch.attach(triggerSwitchPin, INPUT_PULLUP);
        triggerSwitch.interval(debounceTime_ms);
        triggerSwitch.setPressedState(triggerSwitchNormallyClosed);
    }
    if (cycleSwitchPin) {
        cycleSwitch.attach(cycleSwitchPin, INPUT_PULLUP);
        cycleSwitch.interval(pusherDebounceTime_ms);
        cycleSwitch.setPressedState(cycleSwitchNormallyClosed);
    }
    if (selectFireType != NO_SELECT_FIRE) {
        if (select0Pin) {
            select0.attach(select0Pin, INPUT_PULLUP);
            select0.interval(debounceTime_ms);
            select0.setPressedState(false);
        }
        if (select1Pin) {
            select1.attach(select1Pin, INPUT_PULLUP);
            select1.interval(debounceTime_ms);
            select1.setPressedState(false);
        }
        if (select2Pin) {
            select2.attach(select2Pin, INPUT_PULLUP);
            select2.interval(debounceTime_ms);
            select2.setPressedState(false);
        }
    }

    if (dshotMode == DSHOT_OFF) {
        for (int i = 0; i < 4; i++) {
            ESP32PWM::allocateTimer(i);
            servo[i].setPeriodHertz(servoFreq_hz);
        }
        servo[0].attach(board.esc1);
        servo[1].attach(board.esc2);
        servo[2].attach(board.esc3);
        servo[3].attach(board.esc4);
    } else {
        for (int i = 0; i < 4; i++) {
            if (motors[i]) {
                dshot[i].begin(dshotMode, dshotBidirectional, 14); // bitrate, bidirectional, and motor pole count
            }
        }
    }

    // change FPS using select fire switch position at boot time
    if (variableFPS) {
        updateFiringMode();
    }

    fpsMode = firingMode;
    Serial.print("fpsMode: ");
    Serial.println(fpsMode);
    for (int i = 0; i < 4; i++) {
        if (motors[i]) {
            revRPM[i] = revRPMset[fpsMode][i];
            firingRPM[i] = max(revRPM[i] - firingRPMTolerance, minFiringRPM);
            fullThrottleRpmThreshold[i] = revRPM[i] - fullThrottleRpmTolerance;
        }
    }
    idleTime_ms = idleTimeSet_ms[fpsMode];

    if (board.flywheel) {
        pinMode(board.flywheel, OUTPUT);
        if (!brushedFlywheels) {
            digitalWrite(board.flywheel, HIGH);
        }
    }

    for (int count = 0; count < 10000; count++) {
        for (int i = 0; i < 4; i++) {
            if (motors[i]) {
                dshot[i].send_dshot_value(0, NO_TELEMETRIC);
            }
        }
    }

    if (board.nSleep) {
        pinMode(board.nSleep, OUTPUT);
        digitalWrite(board.nSleep, HIGH);
        delayMicroseconds(1000);
        digitalWrite(board.nSleep, LOW);
        delayMicroseconds(30);
        digitalWrite(board.nSleep, HIGH);
    }

    batteryADC.attach(board.batteryADC);
    pusherShuntADC.attach(board.pusherShunt);

    if (wifiDuration_ms > 0) {
        WiFiInit();
    }
}

void loop()
{
    loopStartTimer_us = micros();
    time_ms = millis();
    if (revSwitchPin) {
        revSwitch.update();
    }
    if (triggerSwitchPin) {
        triggerSwitch.update();
    }
    updateFiringMode();
    // changes burst options
    burstLength = burstLengthSet[firingMode];
    burstMode = burstModeSet[firingMode];

    // Transfer data from telemetry serial port to telemetry serial buffer:
    // while (Serial2.available()) {
    //     telemBuffer += Serial2.read(); // this doesn't seem to work - do we need 1k pullup resistor? also is this the most efficient way to do this?
    // }
    // Then parse serial buffer, if serial buffer contains complete packet then update motorRPM value, clear serial buffer, and increment telemMotorNum to get the data for the next motor
    // will we be able to detect the gaps between packets to know when a packet is complete? Need to test and see
    //    Serial.println(telemBuffer);

    if (triggerSwitch.pressed() || (burstMode == BINARY && triggerSwitch.released() && time_ms < triggerTime_ms + binaryTriggerTimeout_ms)) { // pressed and released are transitions, isPressed is for state
        Serial.print(time_ms);
        if (triggerSwitch.pressed()) {
            Serial.print(" trigger pressed, burstMode ");
        } else if (burstMode == BINARY && triggerSwitch.released() && time_ms < triggerTime_ms + binaryTriggerTimeout_ms) {
            Serial.print(" binary trigger released, burstMode ");
        }
        triggerTime_ms = time_ms;
        Serial.print(burstMode);
        Serial.print(" shotsToFire before ");
        Serial.print(shotsToFire);
        if (burstMode == AUTO) {
            shotsToFire = burstLength;
        } else {
            if (shotsToFire < burstLength || shotsToFire == 1) {
                shotsToFire += burstLength;
            }
        }
        Serial.print(" after ");
        Serial.println(shotsToFire);
    } else if (triggerSwitch.released()) {
        if (burstMode == AUTO && shotsToFire > 1) {
            shotsToFire = 1;
        }
    }

    switch (flywheelState) {

    case STATE_IDLE:
        if (batteryVoltage_mv < lowVoltageCutoff_mv && throttleValue[0] == 0 && loopStartTimer_us > 2000000) {
            digitalWrite(board.flywheel, LOW); // cut power to ESCs and pusher
            Serial.print("Battery low, shutting down! ");
            Serial.print(batteryVoltage_mv);
            Serial.println("mv");
            esp_deep_sleep_start(); // go to sleep and never wake up
        }

        if (shotsToFire > 0 || revSwitch.isPressed()) {
            revStartTime_us = loopStartTimer_us;
            memcpy(targetRPM, revRPM, sizeof(targetRPM)); // Copy revRPM to targetRPM
            lastRevTime_ms = time_ms;
            flywheelState = STATE_ACCELERATING;
            currentSpindownSpeed = 0; // reset spindownSpeed
        } else if (time_ms < lastRevTime_ms + idleTime_ms && lastRevTime_ms > 0) { // idle flywheels
            if (currentSpindownSpeed < spindownSpeed) {
                currentSpindownSpeed += 1;
            }
            for (int i = 0; i < 4; i++) {
                if (motors[i]) {
                    targetRPM[i] = max(targetRPM[i] - static_cast<int32_t>((currentSpindownSpeed * loopTime_us) / 1000), idleRPM[i]);
                }
            }
        } else { // stop flywheels
            if (currentSpindownSpeed < spindownSpeed) {
                currentSpindownSpeed += 1;
            }
            for (int i = 0; i < 4; i++) {
                if (motors[i] && targetRPM[i] != 0) {
                    targetRPM[i] = max(targetRPM[i] - static_cast<int32_t>((currentSpindownSpeed * loopTime_us) / 1000), 0);
                }
            }
            PIDIntegral = 0;
            fromIdle = false;
        }
        break;

    case STATE_ACCELERATING:
        // clang-format off
        if (flywheelControl != OPEN_LOOP_CONTROL && time_ms > lastRevTime_ms + (fromIdle ? minFiringDelayIdleSet_ms[fpsMode] : minFiringDelaySet_ms[fpsMode])) {
            // If all motors are at target RPM, update the blaster's state to FULLSPEED.
            if ((!motors[0] || motorRPM[0] > firingRPM[0]) &&
                (!motors[1] || motorRPM[1] > firingRPM[1]) &&
                (!motors[2] || motorRPM[2] > firingRPM[2]) &&
                (!motors[3] || motorRPM[3] > firingRPM[3])
            ) {
                flywheelState = STATE_FULLSPEED;
                fromIdle =  true;
                Serial.println("STATE_FULLSPEED transition 1");
            }
        }
        if ((flywheelControl == OPEN_LOOP_CONTROL
            || (timeOverrideWhenIdling &&
                fromIdle &&
                (!motors[0] || motorRPM[0] > 100) &&
                (!motors[1] || motorRPM[1] > 100) &&
                (!motors[2] || motorRPM[2] > 100) &&
                (!motors[3] || motorRPM[3] > 100)
                )
            )
            && time_ms > lastRevTime_ms + (fromIdle ? firingDelayIdleSet_ms[fpsMode] : firingDelaySet_ms[fpsMode])) {
                flywheelState = STATE_FULLSPEED;
                fromIdle = true;
                Serial.print(time_ms);
                Serial.println(" STATE_FULLSPEED transition, firingDelay time elapsed");
        }
        break;
        // clang-format on

    case STATE_FULLSPEED:
        if (!revSwitch.isPressed() && shotsToFire == 0 && !firing) {
            flywheelState = STATE_IDLE;
            Serial.println("state transition: FULLSPEED to IDLE 1");
        } else if (shotsToFire > 0 || firing) {
            lastRevTime_ms = time_ms;
            switch (pusherType) {

            case PUSHER_MOTOR_CLOSEDLOOP:
                cycleSwitch.update();
                if (shotsToFire > 0 && !firing) { // start pusher stroke
                    pusher->drive(100.0 * pusherVoltage_mv / batteryVoltage_mv, pusherReverseDirection); // drive function clamps the input so it's ok if it's over 100
                    firing = true;
                    pusherTimer_ms = time_ms;
                    Serial.print(time_ms);
                    Serial.println(" pusher stroke starting");
                } else if (firing && cycleSwitch.pressed()) { // when the pusher reaches rear position
                    shotsToFire = max(0, shotsToFire - 1);
                    Serial.print(time_ms);
                    Serial.print(" pusher reached rear, shotsToFire reduced by 1, now ");
                    Serial.println(shotsToFire);
                    pusherTimer_ms = time_ms;
                    if (shotsToFire <= 0) { // brake pusher
                        if (pusherReversePolarityDuration_ms > 0) {
                            pusher->drive(100.0 * pusherReverseBrakingVoltage_mv / batteryVoltage_mv, !pusherReverseDirection); // drive motor backwards to stop faster
                            reverseBraking = true;
                            Serial.print(time_ms);
                            Serial.println(" reverse braking started");
                            //                  firing = false; this doesn't work because this pusher control routine only runs when the flywheels are running, so this causes reverse braking to never end. refactor later?
                        } else {
                            pusher->brake();
                            firing = false;
                            flywheelState = STATE_IDLE; // check later
                            Serial.println("state transition: FULLSPEED to IDLE 2");
                        }
                    } else if (pusherDwellTime_ms > 0) {
                        if (pusherBrakeOnDwell) {
                            pusher->brake();
                        } else {
                            pusher->coast();
                        }
                        pusherDwelling = true;
                    }
                } else if (pusherDwelling) { // dwelling to reduce rate of fire
                    if (time_ms - pusherTimer_ms > pusherDwellTime_ms) { // if we've coasted the pusher for long enough
                        pusher->drive(100.0 * pusherVoltage_mv / batteryVoltage_mv, pusherReverseDirection); // resume pushing
                        pusherDwelling = false;
                    }
                } else if (reverseBraking) { // if we're currently doing reverse braking
                    if (shotsToFire >= 1) { // stop reverse braking and resume firing
                        pusher->drive(100.0 * pusherVoltage_mv / batteryVoltage_mv, pusherReverseDirection); // drive function clamps the input so it's ok if it's over 100
                        firing = true;
                        pusherTimer_ms = time_ms;
                        reverseBraking = false;
                        Serial.print(time_ms);
                        Serial.println(" ending reverse braking, resuming firing");
                    } else if (cycleSwitch.released() && pusherEndReverseBrakingEarly) {
                        Serial.println("Cycle switch released during reverse braking");
                        pusher->brake();
                        reverseBraking = false;
                        firing = false;
                        flywheelState = STATE_IDLE; // check later
                        Serial.println("state transition: FULLSPEED to IDLE 3");
                    } else if (cycleSwitch.pressed()) {
                        Serial.println("Cycle switch pressed during reverse braking");
                        pusher->brake();
                        reverseBraking = false;
                        firing = false;
                        flywheelState = STATE_IDLE; // check later
                        Serial.println("state transition: FULLSPEED to IDLE 4");
                    } else if (time_ms > pusherTimer_ms + pusherReversePolarityDuration_ms) {
                        Serial.print(time_ms);
                        Serial.println(" pusherReverse end of duration");
                        pusher->brake();
                        reverseBraking = false;
                        firing = false;
                        flywheelState = STATE_IDLE; // check later
                        Serial.print(time_ms);
                        Serial.println(" state transition: FULLSPEED to IDLE 5");
                    }
                } else if (!firing && cycleSwitch.released() && pusherReverseOnOverrun) {
                    Serial.println("pusherReverseOnOverrun");
                    pusher->drive(100, !pusherReverseDirection); // drive motor backwards to stop faster
                    reverseBraking = true;
                } else if (firing && time_ms > pusherTimer_ms + pusherStallTime_ms) { // stall protection
                    pusher->coast();
                    shotsToFire = 0;
                    firing = false;
                    flywheelState = STATE_IDLE; // check later
                    Serial.println("Pusher motor stalled!");
                }
                break;

            case PUSHER_SOLENOID_OPENLOOP:
                if (shotsToFire > 0 && !firing && time_ms > pusherTimer_ms + solenoidRetractTime_ms) { // extend solenoid
                    pusher->drive(100, pusherReverseDirection);
                    firing = true;
                    shotsToFire = max(0, shotsToFire - 1);
                    pusherTimer_ms = time_ms;
                    Serial.println("solenoid extending");
                } else if (firing && time_ms > pusherTimer_ms + solenoidExtendTime_ms) { // retract solenoid
                    pusher->coast();
                    firing = false;
                    pusherTimer_ms = time_ms;
                    Serial.println("solenoid retracting");
                }
                break;
            case NO_PUSHER:
                break;
            }
        }
        break;
    }
    batteryADC_mv = batteryADC.readMiliVolts();
    if (voltageAveragingWindow == 1) {
        batteryVoltage_mv = voltageCalibrationFactor * batteryADC_mv * 11;
    } else {
        voltageBuffer[voltageBufferIndex] = voltageCalibrationFactor * batteryADC_mv * 11;
        voltageBufferIndex = (voltageBufferIndex + 1) % voltageAveragingWindow;
        batteryVoltage_mv = 0;
        for (int i = 0; i < voltageAveragingWindow; i++) {
            batteryVoltage_mv += voltageBuffer[i];
        }
        batteryVoltage_mv /= voltageAveragingWindow; // apply exponential moving average to smooth out noise. Time constant ≈ 1.44 ms
    }
    if (wifiState == false) {
        pusherShunt_mv = pusherShuntADC.readMiliVolts();
        pusherCurrent_ma = pusherShunt_mv * 3070 / 1000 - 392; // 3070 current reduction factor for IPROPI, 1k shunt resistor, and the datasheet says the zero offset should be 15mA but experimentally it's 392mA
        pusherCurrentSmoothed_ma = (pusherCurrent_ma * (100 - pusherCurrentSmoothingFactor) + pusherCurrentSmoothed_ma * pusherCurrentSmoothingFactor) / 100;
    }

    switch (flywheelControl) {
    case PID_CONTROL:
        for (int i = 0; i < 4; i++) {
            if (motors[i]) {
                PIDError[i] = targetRPM[i] - motorRPM[i];

                PIDOutput[i] = KP * PIDError[i] + KI * (PIDIntegral + PIDError[i] * loopTime_us / 1000000) + KD * (PIDError[i] - PIDErrorPrior[i]) / loopTime_us * 1000000;
                closedLoopRPM[i] = PIDOutput[i] + motorRPM[i];

                if (throttleValue[i] == 0) {
                    throttleValue[i] = min(maxThrottle, maxThrottle * closedLoopRPM[i] / batteryVoltage_mv * 1000 / motorKv);
                } else {
                    throttleValue[i] = max(min(maxThrottle, maxThrottle * closedLoopRPM[i] / batteryVoltage_mv * 1000 / motorKv),
                        throttleValue[i] - 1);
                }

                PIDErrorPrior[i] = PIDError[i];
                PIDIntegral += PIDIntegral + PIDError[i] * loopTime_us / 1000000;
            }
        }
        break;

    case TWO_LEVEL_CONTROL:
        for (int i = 0; i < 4; i++) {
            if (motors[i]) {
                if (targetRPM[i] == revRPM[i] && motorRPM[i] < fullThrottleRpmThreshold[i]) {
                    throttleValue[i] = maxThrottle;
                } else {
                    throttleValue[i] = max(min(maxThrottle, maxThrottle * targetRPM[i] / batteryVoltage_mv * 1000 / motorKv), 0);
                }
            }
        }
        break;

    case OPEN_LOOP_CONTROL:
        for (int i = 0; i < 4; i++) {
            if (motors[i]) {
                throttleValue[i] = max(min(maxThrottle, maxThrottle * targetRPM[i] / batteryVoltage_mv * 1000 / motorKv), 0);
            }
        }
        break;
    }
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

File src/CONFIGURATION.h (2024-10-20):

#include "DShotRMT.h" // We need this for the dshot modes
#include "boards_config.h" // board pinouts are in this file

// Flywheel Settings
// If variableFPS is true, the following settings are set on boot and locked. Otherwise, it always uses the first mode
bool variableFPS = true;
int32_t revRPMset[3][4] = { { 40000, 40000, 40000, 40000 }, { 25000, 25000, 25000, 25000 }, { 14000, 14000, 14000, 14000 } }; // adjust this to change fps, groups are firingMode 1, 2, 3, and the 4 elements in each group are individual motor RPM
uint32_t idleTimeSet_ms[3] = { 30000, 5000, 2000 }; // how long to idle the flywheels for after releasing the trigger, in milliseconds
uint32_t firingDelaySet_ms[3] = { 150, 125, 100 }; // delay to allow flywheels to spin up before firing dart
uint32_t firingDelayIdleSet_ms[3] = { 125, 100, 80 }; // delay to allow flywheels to spin up before firing dart when starting from idle state
uint32_t spindownSpeed = 30; // RPM per ms

int32_t motorKv = 3200; // critical for closed loop
int32_t idleRPM[4] = { 500, 500, 500, 500 }; // rpm for flywheel idling, set this as low as possible where the wheels still spin reliably
dshot_mode_t dshotMode = DSHOT300; // Options are DSHOT150, DSHOT300, DSHOT600, or DSHOT_OFF. DSHOT300 is recommended, DSHOT150 does not work with either AM32 ESCs or closed loop control, and DSHOT600 seems less reliable. DSHOT_OFF falls back to servo PWM. PWM is not working, probably a ESP32 timer resource conflict with the pusher PWM circuit
bool brushedFlywheels = false; // solder a brushed motor flywheel cage to the ESC+ and Brushed Motor - pads

// Closed Loop Settings
flywheelControlType_t flywheelControl = OPEN_LOOP_CONTROL; // OPEN_LOOP_CONTROL or TWO_LEVEL_CONTROL
const bool motors[4] = {true, true, true, true}; // which motors are hooked up
bool timeOverrideWhenIdling = true; // while idling, fire the pusher after firingDelay_ms even before the flywheels are up to speed
int32_t fullThrottleRpmTolerance = 5000; // if rpm is more than this amount below target rpm, send full throttle. too high and rpm will undershoot, too low and it will overshoot
int32_t firingRPMTolerance = 10000; // fire pusher when all flywheels are within this amount of target rpm. higher values will mean less pusher delay but potentially fire too early
int32_t minFiringRPM = 10000; // overrides firingRPMTolerance for low rpm settings
int32_t minFiringDelaySet_ms[3] = {0, 0, 0}; // when not idling, don't fire the pusher before this amount of time, even if wheels are up to speed. makes the delay more consistent
int32_t minFiringDelayIdleSet_ms[3] = {0, 0, 0}; // same but when idling

// Select Fire Settings
uint32_t burstLengthSet[3] = { 100, 5, 1 };
burstFireType_t burstModeSet[3] = { AUTO, AUTO, BURST };
// burstMode AUTO = stops firing when trigger is released
// burstMode BURST = always completes the burst
// burstMode BINARY = fires one burst when you pull the trigger and another when you release the trigger
// for full auto, set burstLength high (50+) and burstMode to AUTO
// for semi auto, set burstLength to 1 and burstMode to BURST
// for burst fire, set burstLength and burstMode to BURST
// i find a very useful mode is full auto with a 5 dart limit (burstMode AUTO, burstLength 5)

uint32_t binaryTriggerTimeout_ms = 2000; // if you hold the trigger for more than this amount of time, releasing the trigger will not fire a burst


selectFireType_t selectFireType = SWITCH_SELECT_FIRE; // pick NO_SELECT_FIRE, SWITCH_SELECT_FIRE, or BUTTON_SELECT_FIRE
uint8_t defaultFiringMode = 1; // only for SWITCH_SELECT_FIRE, what mode to select if no pins are connected

// Dettlaff Settings
bool printTelemetry = false; // output telemetry over USB serial port for tuning. Enabling this turns on bidirectional dshot
uint32_t lowVoltageCutoff_mv = 2500 * 4; // default is 2.5V per cell * 4 cells because the ESP32 voltage measurement is not very accurate
// to protect your batteries, i reccomend doing the calibration below and then setting the cutoff to 3.2V to 3.4V per cell
float voltageCalibrationFactor = 1.0; // measure the battery voltage with a multimeter and divide that by the "Battery voltage before calibration" printed in the Serial Monitor, then put the result here

// Input Pins, set to 0 if not using
uint8_t triggerSwitchPin = 32; // main trigger pin
uint8_t revSwitchPin = 15; // optional rev trigger
uint8_t cycleSwitchPin = 23; // pusher motor home switch
uint8_t select0Pin = 25; // optional for select fire
uint8_t select1Pin = 0; // optional for select fire
uint8_t select2Pin = 33; // optional for select fire
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

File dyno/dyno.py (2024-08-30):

import os
import argparse
import serial
import serial.tools.list_ports
import matplotlib.pyplot as plt
from matplotlib.animation import FuncAnimation
from matplotlib.ticker import AutoMinorLocator
import datetime
import csv
import glob
import platform
from collections import deque
from threading import Thread, Lock
import numpy.ma as ma

# Configuration variables
BAUD_RATE = 460800
LINE_WIDTH = 0.8  # Line width for individual plots
COMBINED_LINE_WIDTH = 0.4  # Line width for combined plot
MAX_DATA_POINTS = 10000

def get_highest_port():
    system = platform.system()
    if system == "Windows":
        ports = [p.device for p in serial.tools.list_ports.comports() if p.device.startswith("COM")]
    elif system == "Linux":
        ports = [p.device for p in serial.tools.list_ports.comports() if p.device.startswith("/dev/ttyUSB")]
    else:  # Assume macOS or other Unix-like system
        ports = [p.device for p in serial.tools.list_ports.comports() if p.device.startswith("/dev/cu.usbserial-")]
    
    if not ports:
        return None
    return max(ports, key=lambda x: int(''.join(filter(str.isdigit, x))) if any(c.isdigit() for c in x) else 0)

class DynamometerPlotter:
    def __init__(self, log_file=None, print_data=False):
        self.print_data = print_data
        self.log_file = log_file
        self.num_motors = self.determine_num_motors()
        self.expected_values = 3 + 2 * self.num_motors  # time, voltage, current, and (throttle, rpm) for each motor

        px = 1/plt.rcParams['figure.dpi']  # pixel in inches
        self.fig, (self.ax1, self.ax2, self.ax3, self.ax4) = plt.subplots(4, 1, figsize=(1200*px, 800*px), sharex=True)
        self.lines = []
        self.data = deque(maxlen=MAX_DATA_POINTS)
        self.new_run = True
        self.mask_starts = []  # Initialize mask_starts here
        self.data_lock = Lock()
        self.min_max_text = None
        self.start_time = None
        self.start_voltage = None
        self.min_voltage = float('inf')
        self.end_voltage = None
        self.min_throttles = [float('inf')] * self.num_motors
        self.max_throttles = [float('-inf')] * self.num_motors
        self.max_rpms = [float('-inf')] * self.num_motors
        self.max_rpm_overall = 0  # Track the overall maximum RPM
        self.line_width = LINE_WIDTH  # Add this line
        self.mask_starts = []  # Initialize mask_starts here  # Initialize mask_starts here
        self.buffer = []  # Add this line to store data between updates
        self.update_flag = False  # Add this line to control when to update the plot

        if log_file:
            print(f"Reading from log file: {log_file}")
            self.read_from_log()
            self.png_file = log_file.rsplit('.', 1)[0] + '.png'
        else:
            self.serial_port = get_highest_port()
            if not self.serial_port:
                raise ValueError("No suitable serial port found.")
            print(f"Using serial port: {self.serial_port}")
            self.ser = serial.Serial(self.serial_port, BAUD_RATE, timeout=0.1)
            self.output_file = datetime.datetime.now().strftime("%Y-%m-%d_%H:%M:%S") + ".log"
            self.png_file = self.output_file.rsplit('.', 1)[0] + '.png'
            self.running = True
            self.data_thread = Thread(target=self.read_serial_data)
            self.data_thread.start()
        self.mask_starts = []

    def determine_num_motors(self):
        if self.log_file:
            with open(self.log_file, 'r') as f:
                for line in f:
                    if line.strip() and not any(c.isalpha() for c in line):
                        values = line.strip().split(',')
                        return (len(values) - 3) // 2  # Subtract time, voltage, and pusherCurrent, divide by 2 for (throttle, rpm) pairs
        else:
            # For real-time data, we'll determine this when we receive the first data point
            return 0

    def read_from_log(self):
        max_timestamp = 0  # Initialize max_timestamp
        prev_timestamp = None
        with open(self.log_file, 'r') as f:
            for row in csv.reader(f):
                if row and not any(c.isalpha() for c in ''.join(row)):
                    if len(row) == self.expected_values and all(self.is_number(x) for x in row):
                        timestamp = int(row[0])
                        if prev_timestamp is not None and timestamp < prev_timestamp:
                            self.mask_starts.append(len(self.data))  # Add this line to detect new runs
                        self.process_data(row)
                        max_timestamp = max(max_timestamp, timestamp)
                        prev_timestamp = timestamp
        print(f"Finished reading log file. Total data points: {len(self.data)}")
        print(f"Max timestamp value: {max_timestamp}")
        if max_timestamp > 10000:
            print("Timestamp is too large")
            os._exit(0)  # Exit the script immediately
        self.update_plot(0)  # Ensure the plot is updated after reading the log file

    def is_number(self, s):
        try:
            float(s)
            return True
        except ValueError:
            return False

    def process_data(self, row):
        if len(row) != self.expected_values:
            print(f"Ignoring row with unexpected number of values: {row}")
            return  # Ignore lines with unexpected number of values

        time_ms, voltage_mv, pusher_current_ma = int(row[0]), float(row[1]), float(row[2])
        voltage = voltage_mv / 1000
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

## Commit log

2022-03-07 ignore changes to arduino_secrets
2022-03-07 add dshot submodule & arduino.json
2022-03-07 Add v0.1 CAD file
    [Dettlaff_Core_v0.1.step]
2022-03-07 created hardware folder
    [Dettlaff_Core_v0.1.step]
2022-03-07 Fix pin numbering
2022-03-07 reorg hardware folder
    [Dettlaff_Core_v0.1.step]
2022-03-27 Add servo PWM fallback protocol
2022-08-05 v0.3 Schematic
2022-08-28 configuring more switches
2022-08-28 switch from Arduino to PlatformIO
2022-09-03 state machine prototype
2022-09-03 state machine take 2, with pusher motor logic
2022-09-03 solenoid open loop control
2022-09-04 Add Bounce2 directly so we can switch algorithms
2022-09-04 cap throttleValue
2022-12-12 Separated pins out to boards_config file
2023-01-01 Vectorized motor variables, added some pseudocode
2023-01-10 Removed global iterator "i"
    This really doesn't need to be in global scope and just runs the risk of
    cropping up later in a bug. It's more efficient to keep it in local
    scope where the compiler can free that memory once it's done with it
    [main.cpp]
2023-01-11 Wiring instructions
2023-02-26 v0.5 support - new pusher driver abstraction
2023-03-03 reduce max pwm to 98%
2023-03-05 fix pusher driver instantiation
    [main.cpp]
2023-06-10 Fix off by one error with shotsToFire
    [main.cpp]
2023-06-17 Fix targetRPM pointer syntax error
    [main.cpp]
2023-06-17 Fix shotsToFire not decrementing
    [main.cpp]
2023-06-18 Move configuration to separate file
    [CONFIGURATION.h]
2023-06-27 Send dshot value of zero for AM32 ESC support
2023-07-29 Fix Dettlaff wifi access point
    [main.cpp]
2023-07-29 Pusher Reverse Polarity Braking
    [CONFIGURATION.h]
2023-07-29 Applying Clang Format
    [CONFIGURATION.h]
2023-07-29 Adding Dshot rmt to the configuration so that compilation no longer requires a certain order in main.cpp
    [CONFIGURATION.h]
2023-07-31 Auto power off wifi to save power
    [CONFIGURATION.h]
2023-07-31 Initial telemetry code
    [CONFIGURATION.h]
2023-08-03 Fixed critical throttle value bug!
    [CONFIGURATION.h]
2023-08-03 might fix the h bridge pusher turning on at boot?
    [main.cpp]
2023-08-03 am32 vs blheli32 arming
    [CONFIGURATION.h]
2023-08-15 add v0.6 board pins
2023-08-16 add pwm support for at8870 pusher driver
2023-08-17 v0.7 support
    [CONFIGURATION.h]
2023-08-27 Fix servo typo
2023-09-06 Dettlaff selector switch support (#38)
    Added support for select fire and variable settings on boot via a 3 pos
    switch
    ---------
    [CONFIGURATION.h]
2023-09-06 Switch to DrGlaucous's DShotRMT_NEO
2023-09-06 Fix select fire typo
    [CONFIGURATION.h]
2023-09-06 print rpm over serial
    [CONFIGURATION.h]
2023-09-06 move switch pin definitions to configuration.h
    [CONFIGURATION.h]
2023-09-17 Refactor select fire, support FDL style buttons
    [CONFIGURATION.h]
2023-09-19 Fix boot timing for AM32 ESCs
    [main.cpp]
2023-10-08 move wifi later to prevent boot loops
    [main.cpp]
2023-10-29 read battery voltage
    [CONFIGURATION.h]
2023-10-29 measure pusher current
    [CONFIGURATION.h]
2023-10-29 pusher constant voltage. and low voltage cutoff
    [CONFIGURATION.h]
2023-12-19 Update hardware files
    [Dettlaff_Core_v0.1.step]
2024-04-14 Add v0.9 Schematic
    [Dettlaff_Core_v0.1.step]
2024-04-15 added v0.9 option & changed default settings
    [CONFIGURATION.h]
2024-04-16 Add shutdown on battery undervoltage
2024-04-16 Added note about PWM issue
    [CONFIGURATION.h]
2024-04-17 Update wiring instructions
2024-04-17 Update wiring photo
2024-04-18 Remove spindownSpeed
    [CONFIGURATION.h]
2024-04-19 Brushed motor support
    [CONFIGURATION.h]
2024-04-19 comment dshot bidirection setting
    [CONFIGURATION.h]
2024-04-20 Disable bidirectional dshot by default
    [CONFIGURATION.h]
2024-04-23 Check battery voltage at boot
2024-05-06 fix broken arduinoespressif32 version
2024-07-17 lowered battery voltage cutoff to 9V
    [CONFIGURATION.h]
2024-07-17 disabled battery voltage cutoff
    [CONFIGURATION.h]
2024-08-03 update printTelemetry
2024-08-05 Added Optional Pusher Motor Dwell Time
    [CONFIGURATION.h]
2024-08-25 added battery voltage manual calibration, and make low battery check wait 10s after boot
    [CONFIGURATION.h]
2024-08-26 Squashed commit of the following:
    commit 759c5dda6e40439b8a8a5d21f40add01ab413a0f
    Author: ahalekelly <ahalekelly@gmail.com>
    Date: Wed Aug 21 10:05:09 2024 -0700
    print pusher current in telemetry
    commit cfa341bb3f47a31965b5f6be63fc908e02a72d69
    Author: ahalekelly <ahalekelly@gmail.com>
    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
    [CONFIGURATION.h]
2024-08-26 add warning flags, some type fixes
    [main.cpp]
2024-08-26 fix esc ordering
    modified: src/CONFIGURATION.h
    modified: src/boards_config.h
    [CONFIGURATION.h]
2024-08-26 closed loop not working yet, turn it off by default
    [CONFIGURATION.h]
2024-08-26 two level closed loop control
    [CONFIGURATION.h]
2024-08-26 remove fullThrottleRpmMinThreshold
    [CONFIGURATION.h]
2024-08-26 timeOverride = false
    [CONFIGURATION.h]
2024-08-28 separate pusher delays depending on flywheel idling
    [CONFIGURATION.h]
2024-08-30 Fix pusher plot scaling
    [dyno.py]
2024-10-06 Move motors config line up
    [CONFIGURATION.h]
2024-10-06 default to open loop control
    [CONFIGURATION.h]
2024-10-20 Refactored spindown logic to fix bugs
    [CONFIGURATION.h]
2024-10-20 Increase debounce time for trigger switches
    [CONFIGURATION.h]
2024-10-20 Added v0.10 and v0.11 boards
    [CONFIGURATION.h]
2024-10-20 Enable WiFi hotspot by default
    [CONFIGURATION.h]
2024-10-20 make pusher more responsive, and add pusher debug prints
2024-10-20 added binary trigger, renamed bufferMode to burstMode, removed mode 2
    [CONFIGURATION.h]
2024-10-20 Add experimental offset to pusher current measurement
2024-10-20 closed loop fixed!!
    [CONFIGURATION.h]
2024-10-20 removed battery voltage averaging
    [CONFIGURATION.h]
2024-10-20 added minFiringRPM
    [CONFIGURATION.h]
2024-10-21 Add v0.11 Schematic
